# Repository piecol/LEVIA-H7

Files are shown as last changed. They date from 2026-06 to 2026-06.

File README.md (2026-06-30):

# LEVIA H7
Open hardware STM32H743 drone flight controller designed in KiCad.
LEVIA H7 is a six-layer flight controller built around the STM32H743, developed as an open hardware platform for multirotor, fixed-wing and experimental UAV applications.
The repository includes the complete editable KiCad design files, schematics, PCB layout, 3D model, bill of materials and manufacturing files.

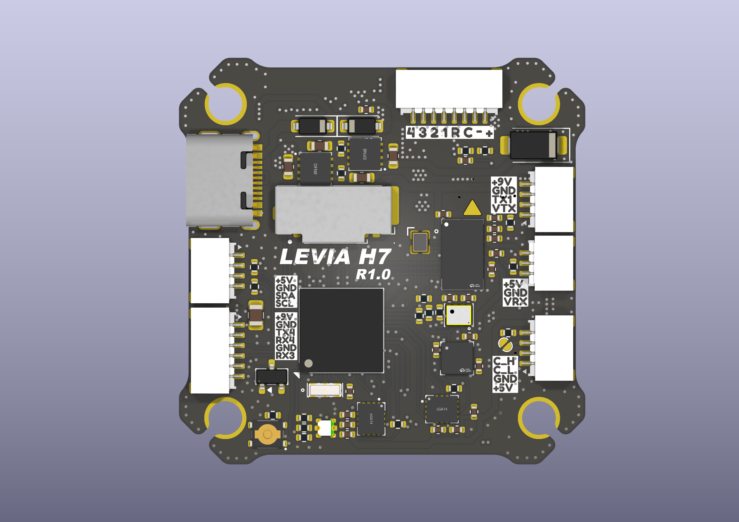
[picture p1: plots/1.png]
Front

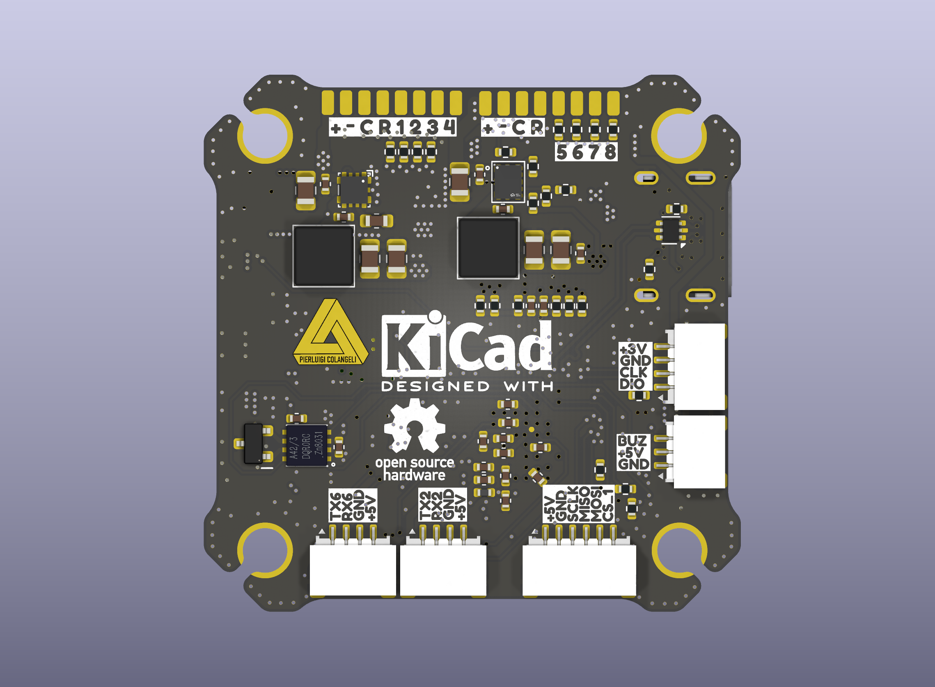
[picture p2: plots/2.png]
Back

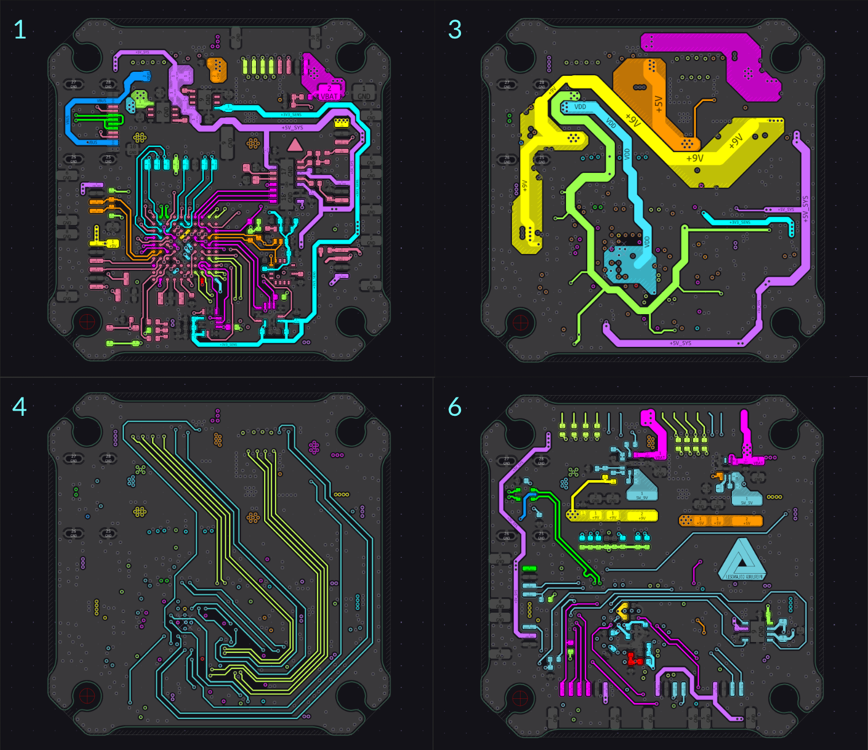
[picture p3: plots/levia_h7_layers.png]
Layers


[!WARNING]
LEVIA H7 is currently an unvalidated hardware design.
Prototype bring-up and flight testing are still pending.
Review the design independently before manufacturing or using it in an aircraft.

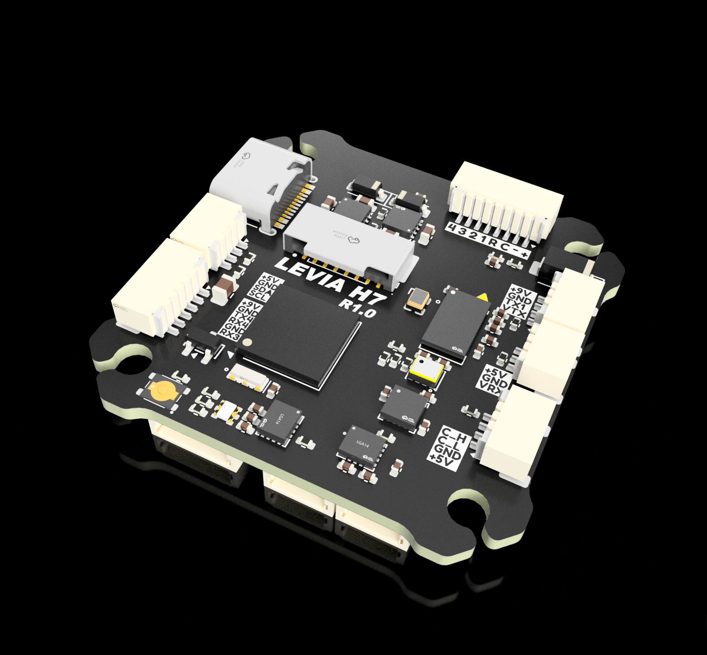
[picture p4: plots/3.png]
Render_F

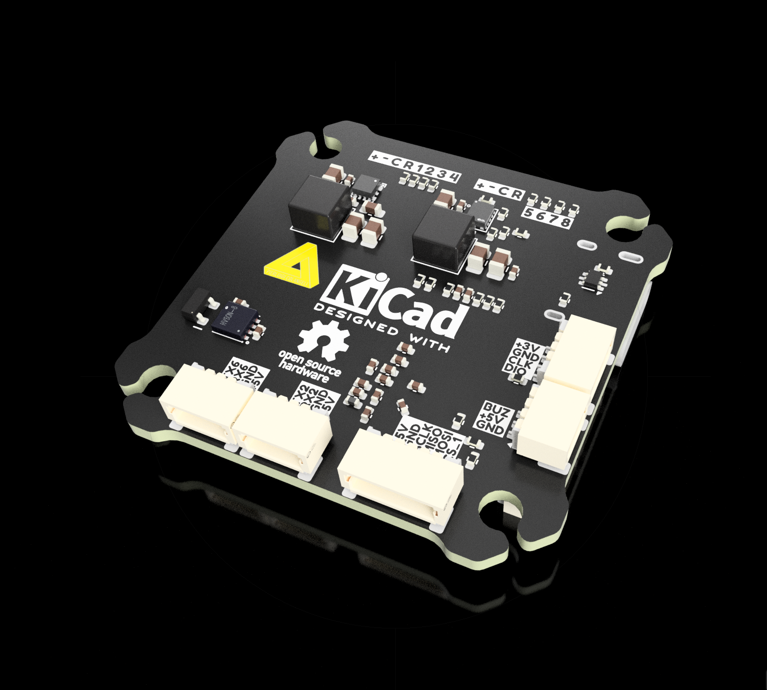
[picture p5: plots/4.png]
Render_B


## Main features

* STM32H743 high-performance microcontroller
* Six-layer PCB
* Eight motor outputs
* Dual ICM-42688-P inertial measurement units
* DPS368 barometric pressure sensor
* IST8310 magnetometer
* microSD interface for onboard logging
* Analog video interface with AT7456E-compatible OSD
* Digital VTX connector for DJI O3/O4-class systems
* CAN interface with selectable 120 Ω termination
* Dedicated RC input connector
* External I²C and SPI expansion connectors
* Two ESC connectors with current sensing and telemetry inputs
* USB-C interface with ESD protection
* Dedicated 5 V and 9 V switching regulators
* Separate 3.3 V regulators for MCU and sensor domains
* Up to 6S battery input

## Project status

The current files should be considered a pre-production engineering revision, not a flight-qualified product.

## Design overview

LEVIA H7 was designed as a general-purpose H7 flight controller rather than as a clone of an existing commercial board.

The architecture follows common flight-controller conventions where useful for firmware compatibility, including standard STM32 peripheral assignments, SDMMC, USB, motor timers and familiar ESC/VTX interfaces.

The following areas were developed independently for LEVIA H7:

* power architecture;
* component placement;
* PCB outline and mechanical design;
* power-distribution network;
* six-layer stackup implementation;
* signal routing;
* grounding strategy;
* design rules and manufacturing preparation.

Publicly available flight-controller schematics, product documentation and firmware hardware definitions were consulted as engineering references.

## Design references

LEVIA H7 is an original KiCad hardware design.

The MatekH743 ArduPilot hardware definition and publicly available flight-controller documentation were used as references for peripheral allocation, firmware compatibility and common interface conventions.

The power architecture, schematic implementation, PCB placement, mechanical design and routing were developed independently.

## Power architecture

LEVIA H7 uses separate power domains for flight-control electronics and external video equipment.

* 5V_SYS supplies the onboard 3.3 V regulators and external low-voltage peripherals.
* 3V3_MCU supplies the STM32H743 and digital logic.
* 3V3_SENS provides a separate supply for onboard sensors.
* 9V is intended for digital video transmitters.
* USB VBUS can power the system through diode OR-ing for configuration and debugging.

The input power architecture supports batteries up to 6S and includes transient-voltage suppression.

## Sensors

Inertial sensing

LEVIA H7 includes two independent ICM-42688-P IMUs connected to separate SPI buses.

The dual-IMU architecture is intended to support sensor redundancy, comparison and firmware-level failover strategies.

## Environmental sensing

The board includes:

* DPS368 barometric pressure sensor;
* IST8310 three-axis magnetometer.

Additional environmental sensing may be considered in future revisions.

## Interfaces

Motor and ESC connections

LEVIA H7 provides two ESC connectors:

* motors 1–4 with current sensing and ESC telemetry;
* motors 5–8 with an independent current input and telemetry UART.

[!CAUTION]
ESC connector pinouts are not universally standardized. Verify VBAT, GND and signal ordering before connecting an ESC.

## Video

The board supports both:

* analog video with onboard OSD;
* digital VTX systems through a dedicated 9 V connector and UART interfaces.

## Expansion

External interfaces include:

* I²C;
* SPI with two chip-select signals;
* CAN;
* UART-based RC input;
* buzzer;
* LED output;
* auxiliary ADC inputs.

The expansion connectors provide 5 V power, while their digital logic operates at 3.3 V.

## PCB

The PCB uses a six-layer stackup with dedicated ground-reference layers.

The layout was developed and documented progressively, with particular attention to:

* uninterrupted signal return paths;
* switching-regulator current loops;
* IMU power integrity;
* separation of analog and switching nodes;
* USB differential routing;
* SDMMC routing;
* motor and telemetry signal grouping.

## Repository contents
```bash
LEVIA-H7/
├── LEVIA_H7.kicad_pro       KiCad project
├── LEVIA_H7.kicad_sch       Top-level schematic
├── LEVIA_H7.kicad_pcb       PCB layout
├── LEVIA_H7.kicad_dru       Custom design rules
├── *.kicad_sch              Hierarchical schematic sheets
├── LEVIA_H7.pdf             Exported schematic
├── LEVIA_H7.step            3D board model
├── bom/                     Bill of materials
├── jlcpcb/                  JLCPCB manufacturing files
├── nextpcb/                 NextPCB manufacturing files
├── plots/                   PCB images and renders
└── LICENSE.txt              CERN-OHL-S-2.0 license
```

## Viewing the design

The project can be opened locally with KiCad 10.

The schematic and PCB can also be inspected directly in a browser through KiCanvas:

KiCanvas: https://kicanvas.org/?repo=https%3A%2F%2Fgithub.com%2Fpiecol%2FLEVIA-H7

No KiCad installation is required for browser-based inspection.

## Manufacturing

Manufacturing exports are included for convenience, but they should not be treated as production-validated files.

Before ordering:

1. review the schematic and PCB independently;
2. verify connector orientation and pin numbering;
3. confirm all selected component variants and footprints;
4. review assembly substitutions;
5. run the latest ERC and DRC;
6. verify the fabrication stackup and controlled-impedance requirements;
7. inspect Gerber and drill files with an independent viewer.

Please use GitHub Issues for review notes, potential errors and proposed improvements.

## License

LEVIA H7 hardware design files are released under the:

CERN Open Hardware Licence Version 2 — Strongly Reciprocal

See LICENSE.txt for the complete license text.

Any redistribution or modified version must comply with the conditions of CERN-OHL-S-2.0.

## Disclaimer

This project is provided without warranty.

LEVIA H7 is experimental hardware intended for engineering, educational and research use.

UAV systems can cause property damage, injury or loss of the aircraft. Anyone manufacturing, modifying or operating this design is responsible for independently validating its safety and regulatory compliance.

⸻

Designed by Pierluigi Colangeli, PhD

Hardware design · Embedded systems · Open hardware

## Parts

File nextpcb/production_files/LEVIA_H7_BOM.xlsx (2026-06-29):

LEVIA_H7
Reference | Qty | Value | MPN | Manufacturer | Footprint | LCSC Part | Datasheet | Notes
C45,C46 | 2 | 10n | CL05B103KB5NNNC | Samsung Electro-Mechanics | Capacitor_SMD:C_0402_1005Metric | C15195 |  | Alternative ok - not critical
C1,C4,C5,C6,C9,C10,C17,C20,C21,C26,C28,C33,C34,C35,C38,C39,C40,C43,C44,C47,C48,C49,C50,C54 | 24 | 100n | GRM022R60J104KE15D | Murata Electronics | Capacitor_SMD:C_0402_1005Metric | C1525 |  | Alternative ok - not critical
C15,C16 | 2 | 100n | GRM022R60J104KE15D | Murata Electronics | Capacitor_SMD:C_0402_1005Metric | C307331 |  | Alternative ok - not critical
C3,C7,C53 | 3 | 1u | CL05A105KA5NQNC | Samsung Electro-Mechanics | Capacitor_SMD:C_0402_1005Metric | C52923 |  | Alternative ok - not critical
C18 | 1 | 1u | CL10A105KB8NNNC | Samsung Electro-Mechanics | Capacitor_SMD:C_0603_1608Metric | C15849 |  | Alternative ok - not critical
C8,C11 | 2 | 2.2u | CL05A225MQ5NSNC | Samsung Electro-Mechanics | Capacitor_SMD:C_0402_1005Metric | C12530 |  | Alternative ok - not critical
L1,L2 | 2 | 2.2u | XGL4020-222MEC | Coilcraft | Inductor_SMD:L_Coilcraft_XAL4030-XXX | C6012410 | ~
C2,C12,C41,C42,C51 | 5 | 4.7u | CL05A475MP5NRNC | Samsung Electro-Mechanics | Capacitor_SMD:C_0402_1005Metric | C23733 |  | Alternative ok - not critical
C29,C30,C31,C32 | 4 | 4.7u | CL10A475KO8NNNC | Samsung Electro-Mechanics | Capacitor_SMD:C_0603_1608Metric | C19666 |  | Alternative ok - not critical
C13,C14 | 2 | 10u | GRM21BR61H106KE43L | Murata Electronics | Capacitor_SMD:C_0805_2012Metric | C440198 |  | Alternative ok - not critical
C36,C37 | 2 | 10u | CL05A106MQ5NUNC | Samsung Electro-Mechanics | Capacitor_SMD:C_0402_1005Metric | C15525 |  | Alternative ok - not critical
C22,C24,C25,C27,C52 | 5 | 22u | CL21A226MAQNNNE | Samsung Electro-Mechanics | Capacitor_SMD:C_0805_2012Metric | C45783 |  | Alternative ok - not critical
R42,R43,R44,R45,R46,R47,R48,R49 | 8 | 10R | 0402WGF100JTCE | UNI-ROYAL(Uniroyal Elec) | Resistor_SMD:R_0402_1005Metric | C25077 |  | Alternative ok - not critical
R22,R23 | 2 | 75R | 0402WGF750JTCE | UNI-ROYAL(Uniroyal Elec) | Resistor_SMD:R_0402_1005Metric | C25133 |  | Alternative ok - not critical
R24 | 1 | 120R | 0402WGF1200TCE | UNI-ROYAL(Uniroyal Elec) | Resistor_SMD:R_0402_1005Metric | C25079 |  | Alternative ok - not critical
R4,R5,R6 | 3 | 220R | 0402WGF2200TCE | UNI-ROYAL(Uniroyal Elec) | Resistor_SMD:R_0402_1005Metric | C25091 |  | Alternative ok - not critical
R11,R34 | 2 | 1K | 0402WGF1001TCE | UNI-ROYAL(Uniroyal Elec) | Resistor_SMD:R_0402_1005Metric | C11702 |  | Alternative ok - not critical
R25,R26,R30,R31 | 4 | 4.7K | 0402WGF4701TCE | UNI-ROYAL(Uniroyal Elec) | Resistor_SMD:R_0402_1005Metric | C25900 |  | Alternative ok - not critical
R1,R2 | 2 | 5.1K | 0402WGF5101TCE | UNI-ROYAL(Uniroyal Elec) | Resistor_SMD:R_0402_1005Metric | C25905 |  | Alternative ok - not critical
R3,R8,R10,R19,R20,R21,R27,R28,R32,R35,R36,R37,R38,R39,R40,R41 | 16 | 10K | 0402WGF1002TCE | UNI-ROYAL(Uniroyal Elec) | Resistor_SMD:R_0402_1005Metric | C25744 |  | Alternative ok - not critical
R16 | 1 | 12.4K | 0402WGF1242TCE | UNI-ROYAL(Uniroyal Elec) | Resistor_SMD:R_0402_1005Metric | C11692 |  | Alternative ok - not critical
R12 | 1 | 16.5k | 0402WGF1652TCE | UNI-ROYAL(Uniroyal Elec) | Resistor_SMD:R_0402_1005Metric | C25857 | ~ | Alternative ok - not critical
R7,R9,R15,R29 | 4 | 100K | 0402WGF1003TCE | UNI-ROYAL(Uniroyal Elec) | Resistor_SMD:R_0402_1005Metric | C25741 | ~ | Alternative ok - not critical
Y1 | 1 | 8MHz | CSTNE8M00GH5C000R0 | muRata(村田) | EasyEDA:OSC-SMD_3P-L3.2-W1.3-P1.20-L | C341525 | https://lcsc.com/product-detail/Others_Murata-Electronics-CSTNE8M00GH5C000R0_C341525.html | Alternative ok - not critical
D3,D4 | 2 | 1N5819WL | 1N5819W | TECH PUBLIC | Diode_SMD:D_SOD-123 | C2905650 | https://datasheet.lcsc.com/lcsc/2204281430_Guangdong-Hottech-1N5819WS_C191023.pdf | Alternative ok - not critical
FB1 | 1 | 600Ω@100MHz | FCM1608KF-601T02 | TAI-TECH | Inductor_SMD:L_0402_1005Metric | C127281 |  | Alternative ok - not critical
U9 | 1 | AT7456ELAH | AT7456ELAH | 杭州中科微 | EasyEDA:LGA-16_L6.8-W4.0-P0.65-TL-2EP | C42388749 | https://www.lcsc.com/datasheet/C42388749.pdf
Q1 | 1 | AO3400A | AO3400A | Alpha & Omega Semicon | Package_TO_SOT_SMD:SOT-23 | C20917 | http://www.aosmd.com/pdfs/datasheet/AO3400A.pdf | Alternative ok - not critical
U6,U7 | 2 | AP7361C-33FGE-7 | AP7361C-33FGE-7 | DIODES(美台) | EasyEDA:DFN-8_L3.0-W3.0-P0.65-BL-EP | C151007 | https://lcsc.com/product-detail/Low-Dropout-Regulators-LDO_DIODES_AP7361C-33FGE-7_AP7361C-33FGE-7_C151007.html
U16 | 1 | DPS368XTSA1 | DPS368XTSA1 | Infineon(英飞凌) | EasyEDA:LGA-8_L2.5-W2.0-P0.65-TR_DPS368 | C3232508 | https://www.lcsc.com/datasheet/C3232508.pdf
USB1 | 1 | HC-TYPE-C-16P-01M | HC-TYPE-C-16P-01M | HCTL | EasyEDA:USB-C-SMD_HCTL_HC-TYPE-C-16P-01M | C2894899 |  | Alternative ok - not critical
U14,U15 | 2 | ICM-42688-P | ICM-42688-P | TDK InvenSense(应美盛) | EasyEDA:LGA-14_L3.0-W2.5-P0.50-TL | C1850418 | https://www.lcsc.com/datasheet/C1850418.pdf
U17 | 1 | IST8310 | IST8310 | iSentek | EasyEDA:LGA-16_L3.0-W3.0-P0.50-BL_SQ | C2683055 | https://www.lcsc.com/datasheet/C2683055.pdf
D1 | 1 | LED_RGB_EP | 19-337/R6GHBHC-M01/2T | EVERLIGHT(亿光) | EasyEDA:LED-ARRAY-SMD_6P-L1.6-W1.6-TL | C131204 | https://lcsc.com/product-detail/Light-Emitting-Diodes-LED_Everlight-Elec-19-337-R6GHBHC-M01-2T_C131204.html | Alternative ok - not critical
U4 | 1 | LMR43620R5RPER | LMR43620R5RPER | TI(德州仪器) | EasyEDA:VQFN-9_L2.1-W2.1-P0.50-TL | C32712896 | https://www.lcsc.com/datasheet/C32712896.pdf
U5 | 1 | LMR604303SRAKRQ1 | LMR604303SRAKRQ1 | TI(德州仪器) | EasyEDA:WQFN-9_L2.5-W2.0_RAK0009A | C49292342 | https://www.lcsc.com/datasheet/C49292342.pdf
D6 | 1 | PESD2CAN | PESD2CANFD24V-TR | Nexperia | PCM_Package_TO_SOT_SMD_AKL:SOT-23 | C552486 | https://www.tme.eu/Document/ad02fbf39ace74a5161accc984238198/PESD2CAN.pdf
SW2 | 1 | RKCGG140SMTRLFS | RKCGG140SMTRLFS | C&K | EasyEDA:SW-SMD_4P-L3.0-W2.6-P1.80-LS3.5 | C2927792 | https://www.lcsc.com/datasheet/C2927792.pdf | Alternative ok - not critical
U12 | 1 | SIT1051TK/3 | TJA1051TK/3,118 | NXP(恩智浦) | EasyEDA:HVSON-8_L3.0-W3.0-P0.65-BL-EP | C124020 | https://lcsc.com/product-detail/CAN_NXP_TJA1051TK-3-118_TJA1051TK-3-118_C124020.html | Alternative ok - not critical
D2 | 1 | SMAJ30CA | SMAJ30CA-13-F | Diodes Incorporated | Diode_SMD:D_SMA | C134980 | https://www.littelfuse.com/media?itemid=75e32973-b177-4ee3-a0ff-cedaf1abdb93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 | Alternative ok - not critical
U2 | 1 | STM32H743VIHx | STM32H743VIH6 | STMicroelectronics | Package_BGA:TFBGA-100_8x8mm_Layout10x10_P0.8mm | C964146 | https://www.st.com/resource/en/datasheet/stm32h743vi.pdf
J1 | 1 | TF-028-H265 | TF-028-H265 | HANBO(汉博) | EasyEDA:TF-SMD_TF-021B-H265 | C5310496 | https://www.we-online.com/components/products/datasheet/693072010801.pdf | Alternative ok - not critical
U1 | 1 | USBLC6-2P6 | TPUSBLC6-2P6 | TECH PUBLIC | Package_TO_SOT_SMD:SOT-666 | C2682291 | https://www.st.com/resource/en/datasheet/usblc6-2.pdf | Alternative ok - not critical
Y2 | 1 | XL7EL89COI-111YLC-27M | XL7EL89COI-111YLC-27M | YXC(扬兴晶振) | Crystal:Crystal_SMD_2016-4Pin_2.0x1.6mm | C18214311 | https://www.lcsc.com/datasheet/C18214311.pdf | Alternative ok - not critical
U11,U21 | 2 | ZX-SH1.0-3PWT | ZX-SH1.0-3PWT | Megastar(兆星) | EasyEDA:CONN-SMD_3P-P1.00_MEGASTAR_ZX-SH1.0-3PWT | C7430445 | https://www.lcsc.com/datasheet/C7430445.pdf | Alternative ok - not critical
U3,U8,U10,U13,U18,U24 | 6 | ZX-SH1.0-4PWT | ZX-SH1.0-4PWT | Megastar(兆星) | EasyEDA:CONN-SMD_4P-P1.00_MEGASTAR_ZX-SH1.0-4PWT | C7430446 | https://www.lcsc.com/datasheet/C7430446.pdf | Alternative ok - not critical
U19,U20 | 2 | ZX-SH1.0-6PWT | ZX-SH1.0-6PWT | Megastar(兆星) | EasyEDA:CONN-SMD_6P-P1.00_MEGASTAR_ZX-SH1.0-6PWT | C7430448 | https://www.lcsc.com/datasheet/C7430448.pdf | Alternative ok - not critical
U22 | 1 | ZX-SH1.0-8PWT | ZX-SH1.0-8PWT | Megastar(兆星) | EasyEDA:CONN-SMD_8P-P1.00_MEGASTAR_ZX-SH1.0-8PWT | C7430450 | https://www.lcsc.com/datasheet/C7430450.pdf | Alternative ok - not critical

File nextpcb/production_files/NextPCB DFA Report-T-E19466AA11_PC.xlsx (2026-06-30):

NEXTPCB DFA report
Project Number：LEVIA_H7 |  | Prepared by: chunxiang |  |  |  |  | Date: 20260630
Item | Problem description 问题描述 | Reference location 影响位置 | MPN 物料名称 | Impact 影响 | Image 图片 | NextPCB Suggestion 建议 | Customer feedback 客户反馈 |  | Severity 严重度 | Status 状态
1 | The clearance is too big in Gerber. | U1 | / | The component can't be 100% soldered on the board, which will cause soldeirng issue. |  | Please modify the clearance to 0.7mm. |  | Changed footprint to better match component | Middle
2 | Could you please provide the dimension of 19-337/R6GHBHC-M01/2T? We can't find it from internet. | D1 | / | We are not sure whether the component can be 100% soldered or not, it seems the clearance is too big. |  | Please confirm the footprint or modify the clearance to 0.15mm. |  | The footprint looks fine, it should be compliant with the manufacturer specs https://www.everlighteurope.com/product-details?id=3322&name=19-337%2FR6GHBHC-M01%2F2T&category=Visible+SMD | Middle
3 | The pcakage is 01005 while the footprint is 0402. | C15,C16 C1,C4,C5,C6,C9,C10,C17,C20,C21,C26,C28,C33,C34,C35,C38,C39,C40,C43,C44,C47,C48,C49,C50,C54 | / | Can't be soldered at all. |  | Please modify the footprint to 01005 or provide a new part number which package is 0402. |  | Samsung Electro-Mechanics - CL05B104KB54PNC - C307331 | High
4 | The pad in Gerber is not match with datasheet. | J1 | / | The component may can't be 100% soldered on the board, which will cause soldeirng issue. |  | Please modify the pad accoridng to datasheet. | Modified according to data sheet |  | Middle
5 | The package is 0603 while the footprint is 0402. | FB1 | / | The pad is too small. |  | Please modify the footprint to 0603 or provide a new part number which package is 0402. |  | Murata Electronics - BLM15BD601SN1D - C337875 | High
6 | When you placed the order you chose tented vias while there are vias in the pads, see attach. | via processing | / | The tin may flow into the vias and cause soldeirng issue. |  | Please remove these vias from the pads. | Removed vias as suggested |  | Middle
7 | Is there any soldering direction requirement for L1,L2? | L1,L2 | / | The silk is not clear so we are not sure. |  | Please confirm. |  | Pin1 of the two inductors faces the north side, I added a small silkscreen segment as mark | Middle

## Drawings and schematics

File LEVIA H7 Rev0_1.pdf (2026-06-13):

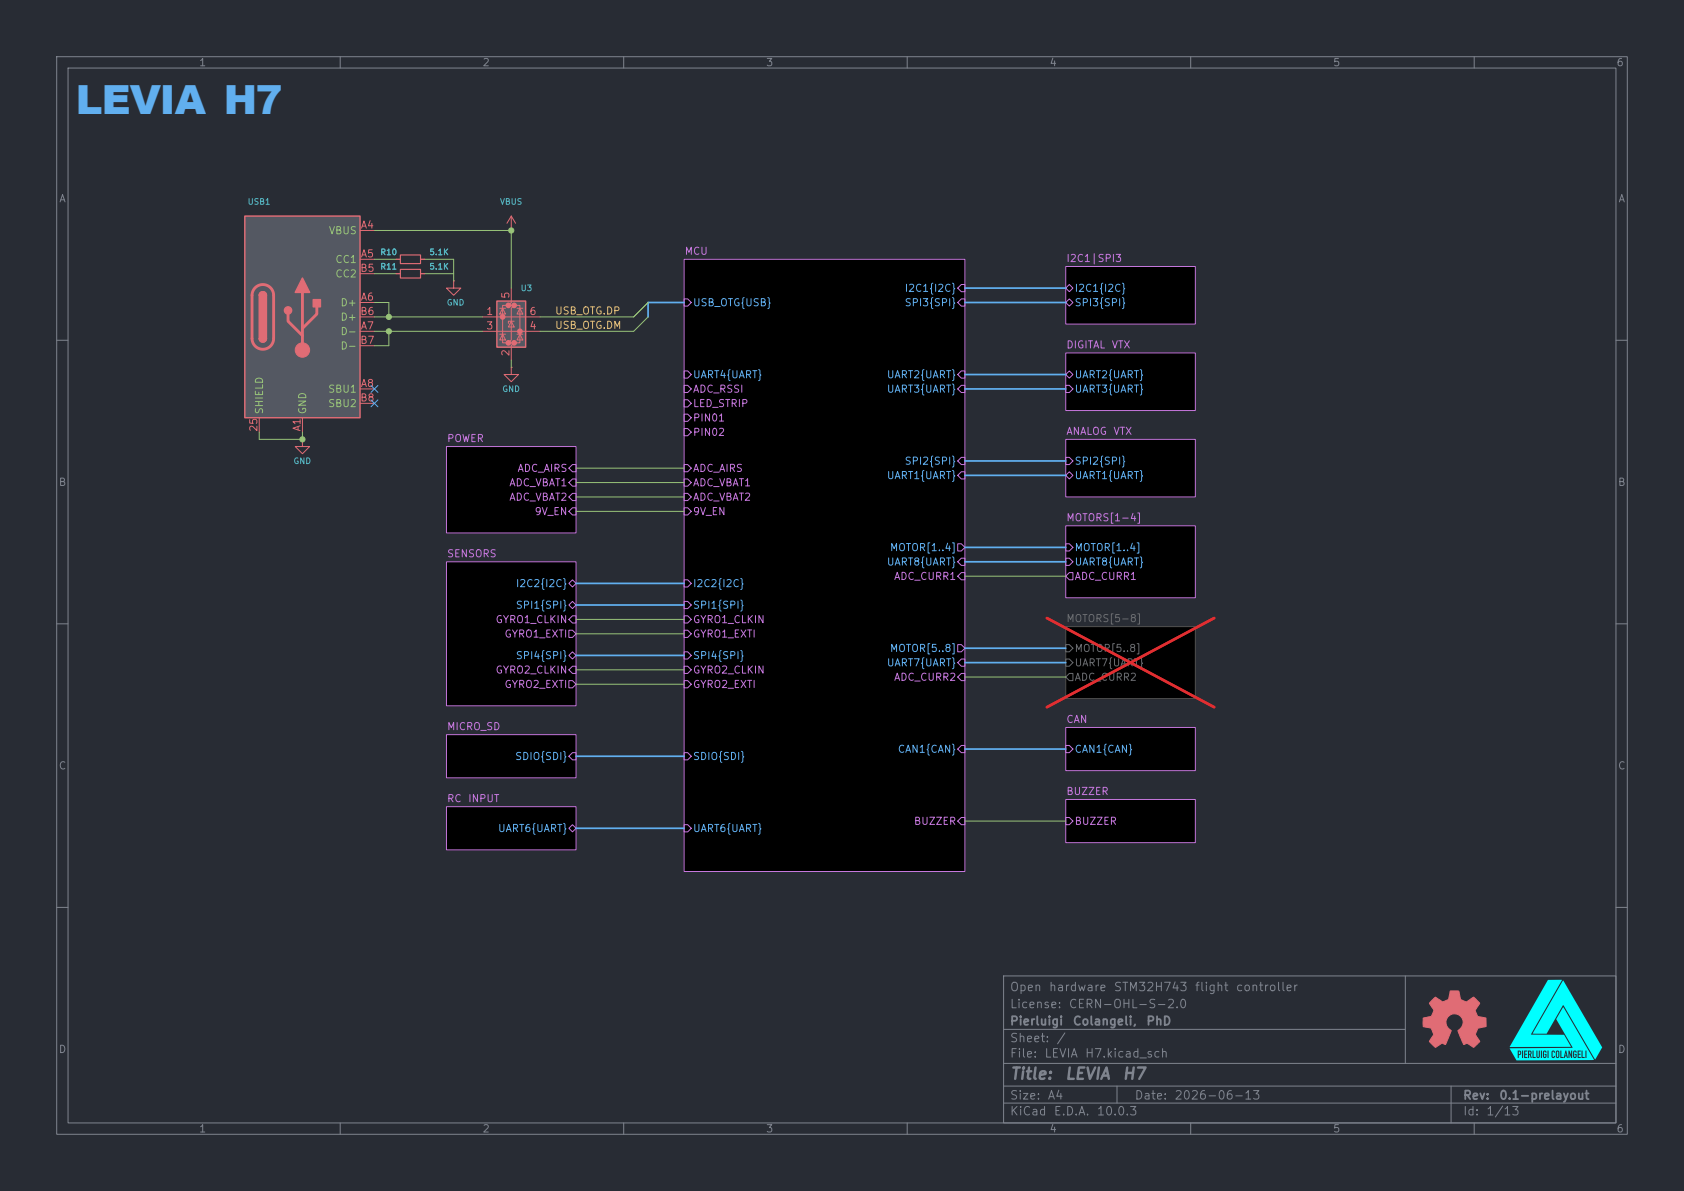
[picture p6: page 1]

Open hardware STM32H743 flight controller
License: CERN-OHL-S-2.0
Pierluigi Colangeli, PhD
Sheet: /
File: LEVIA H7.kicad_sch
Title: LEVIA H7

Size: A4 | Rev: 0.1-prelayout
KiCad E.D.A. 10.0.3 | Id: 1/13

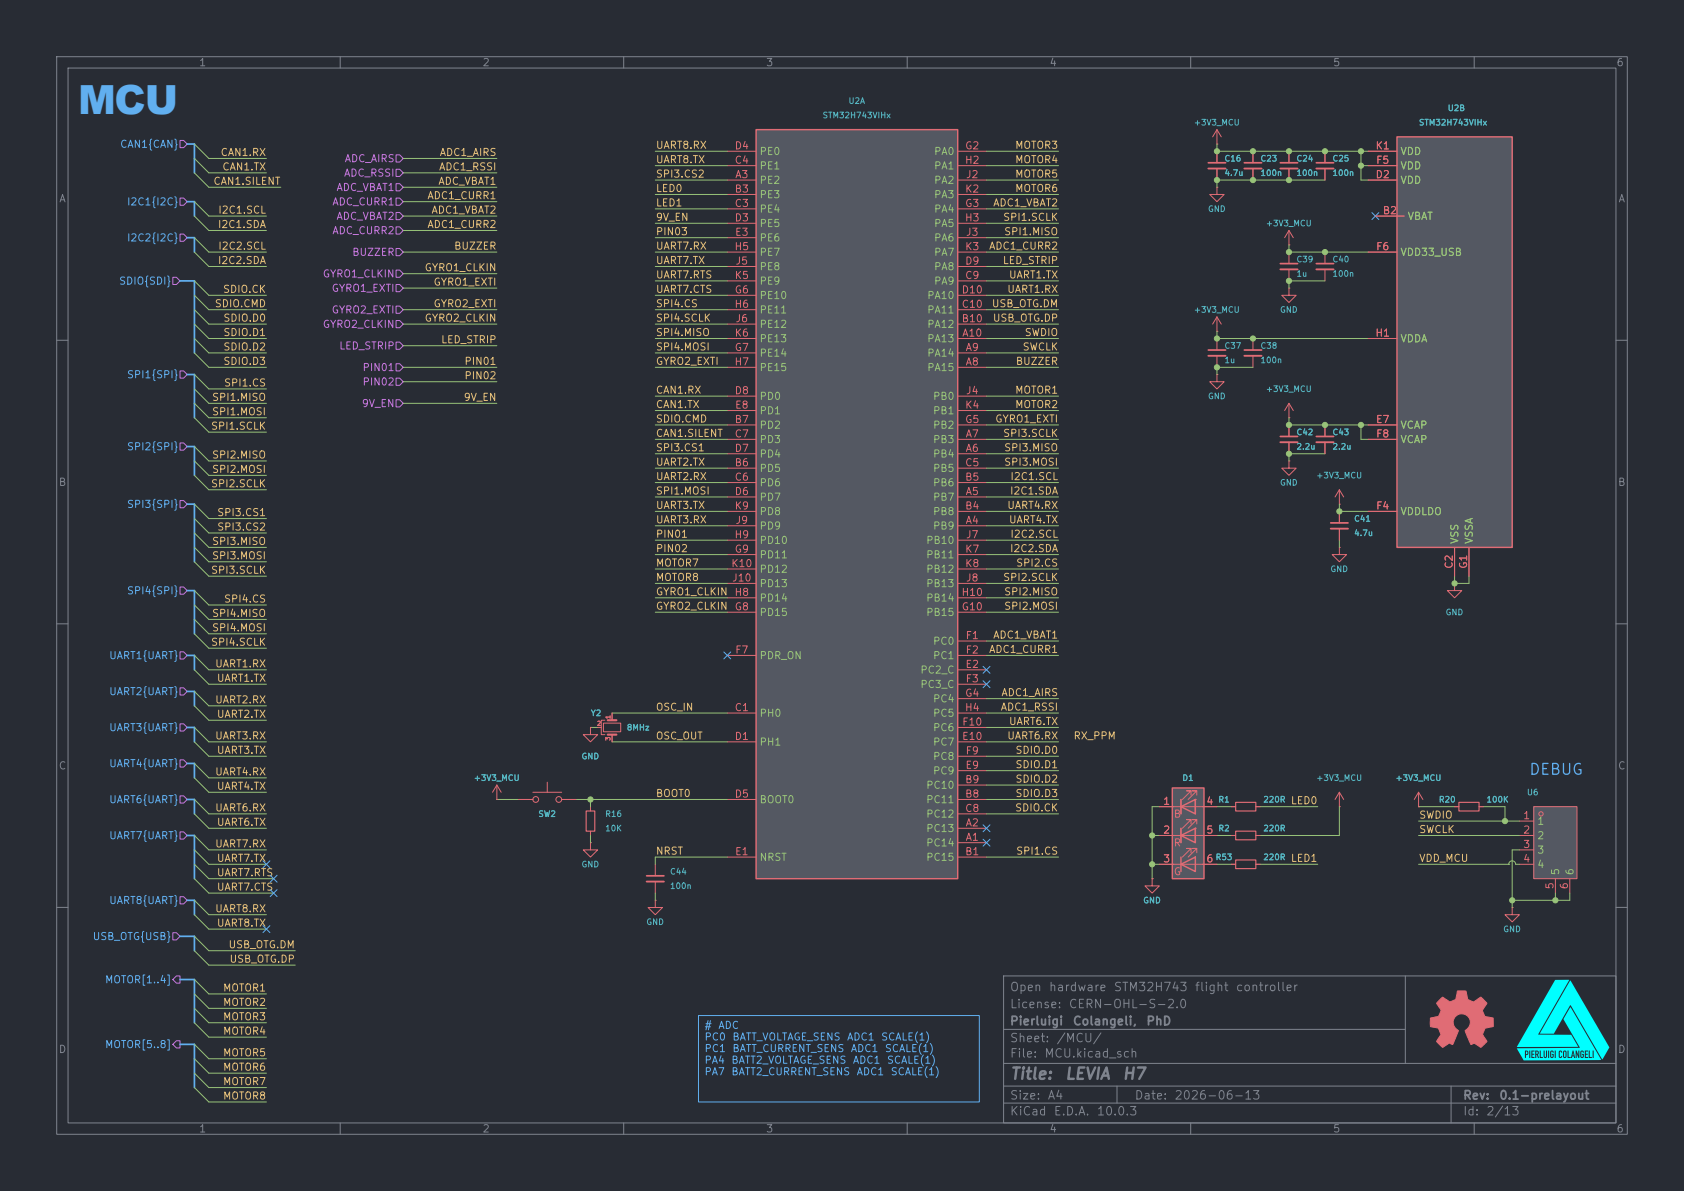
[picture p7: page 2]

PC0 BATT_VOLTAGE_SENS ADC1 SCALE(1) PC1 BATT_CURRENT_SENS ADC1 PA4 BATT2_VOLTAGE_SENS ADC1 PA7 BATT2_CURRENT_SENS ADC1 MCU
UART1.TX CAN1.SILENT SDIO.CK

SPI4.SCLK
ADC1_CURR1 UART7.RX UART6.RX UART3.TX UART4.RX

Open hardware STM32H743 flight controller
License: CERN-OHL-S-2.0
Pierluigi Colangeli, PhD
Sheet: /MCU/
File: MCU.kicad_sch
Title: LEVIA H7

Size: A4 | Rev: 0.1-prelayout
KiCad E.D.A. 10.0.3 | Id: 2/13

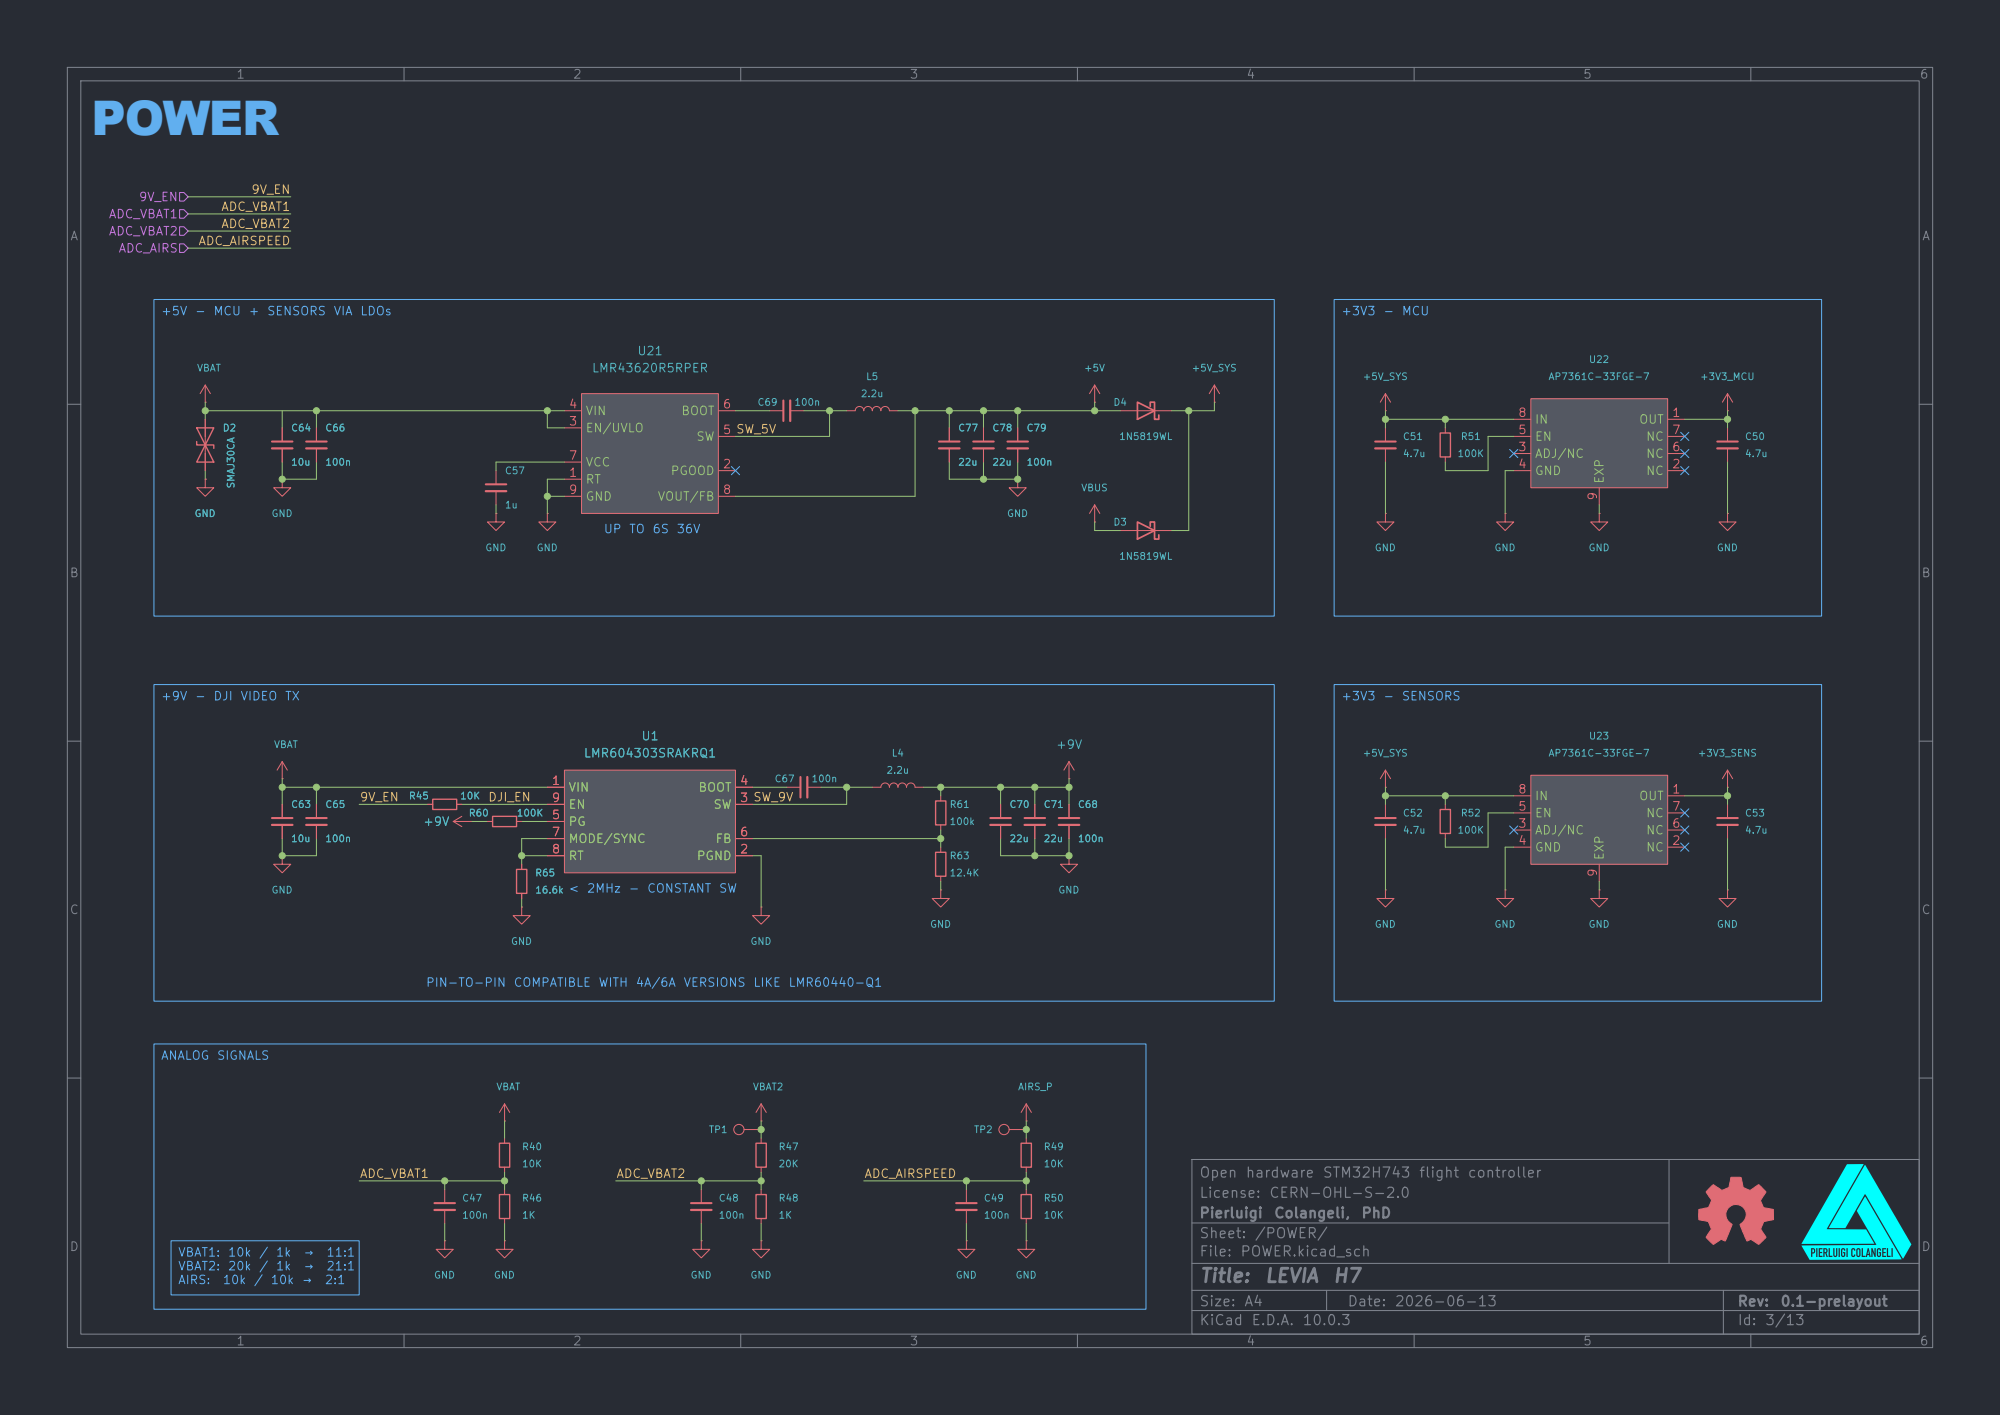
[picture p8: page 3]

Open hardware STM32H743 flight controller +9V

Size: A4 | Rev: 0.1-prelayout
KiCad E.D.A. 10.0.3 | Id: 3/13

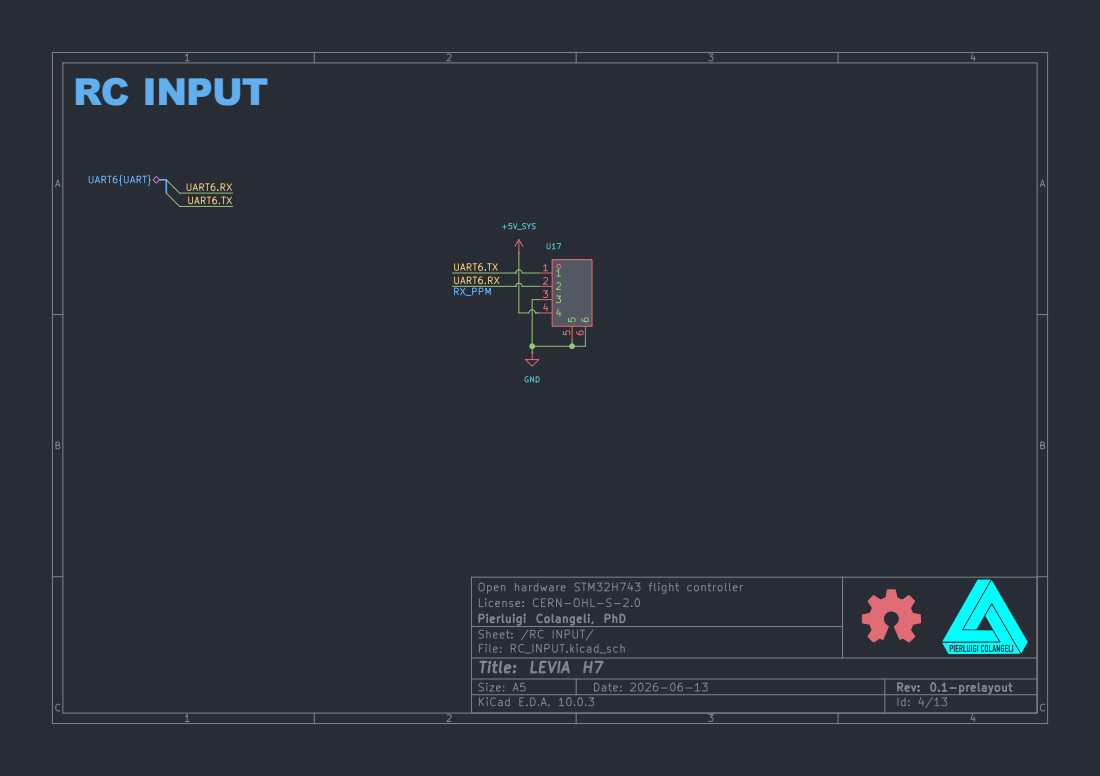
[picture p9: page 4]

Open hardware STM32H743 flight controller 1
RX_PPM

Size: A5 | Rev: 0.1-prelayout | C Date: 2026-06-13
KiCad E.D.A. 10.0.3 | Id: 4/13

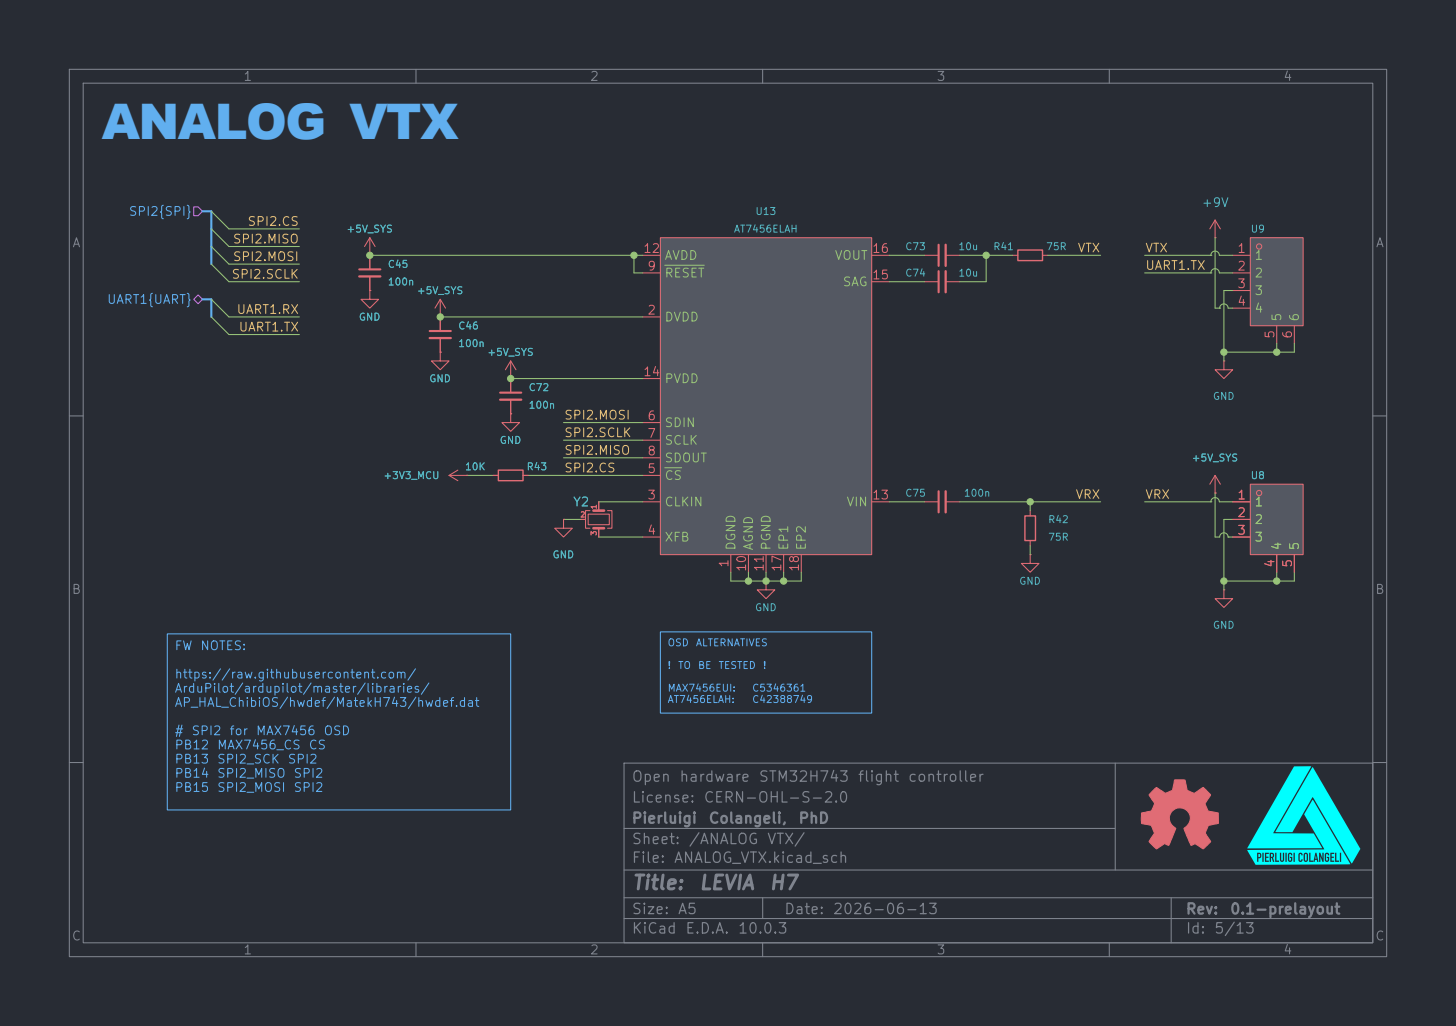
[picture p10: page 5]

Open hardware STM32H743 flight controller DGND

ArduPilot/ardupilot/master/libraries/
AP_HAL_ChibiOS/hwdef/MatekH743/hwdef.dat

Size: A5 | Rev: 0.1-prelayout | C Date: 2026-06-13
KiCad E.D.A. 10.0.3 | Id: 5/13

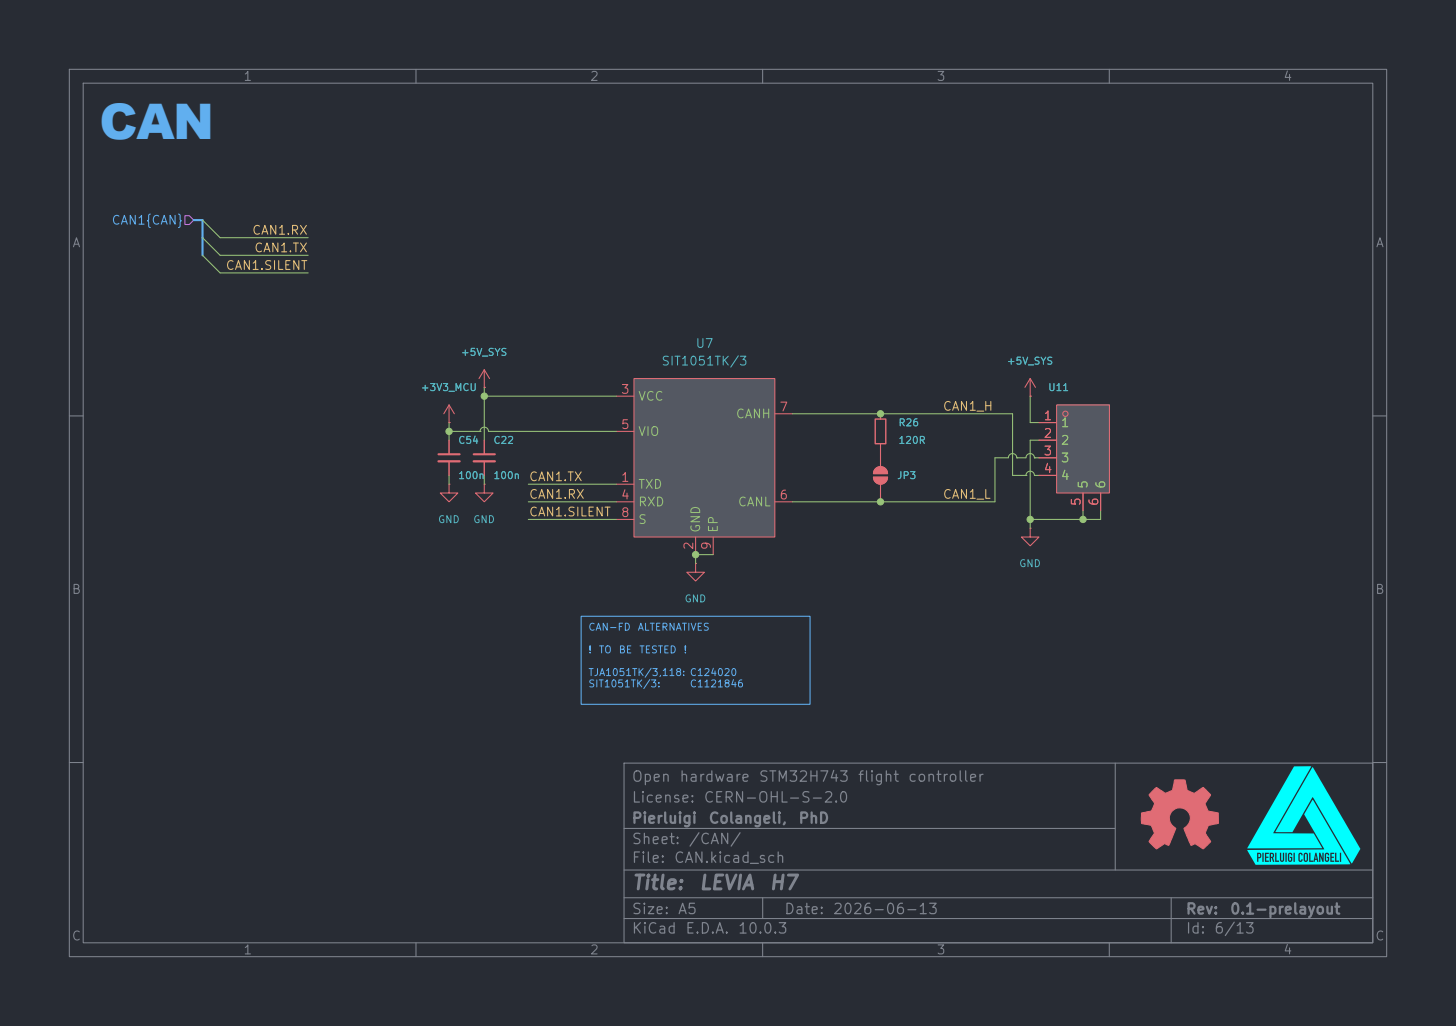
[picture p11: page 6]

Size: A5 | Rev: 0.1-prelayout | C Date: 2026-06-13
KiCad E.D.A. 10.0.3 | Id: 6/13

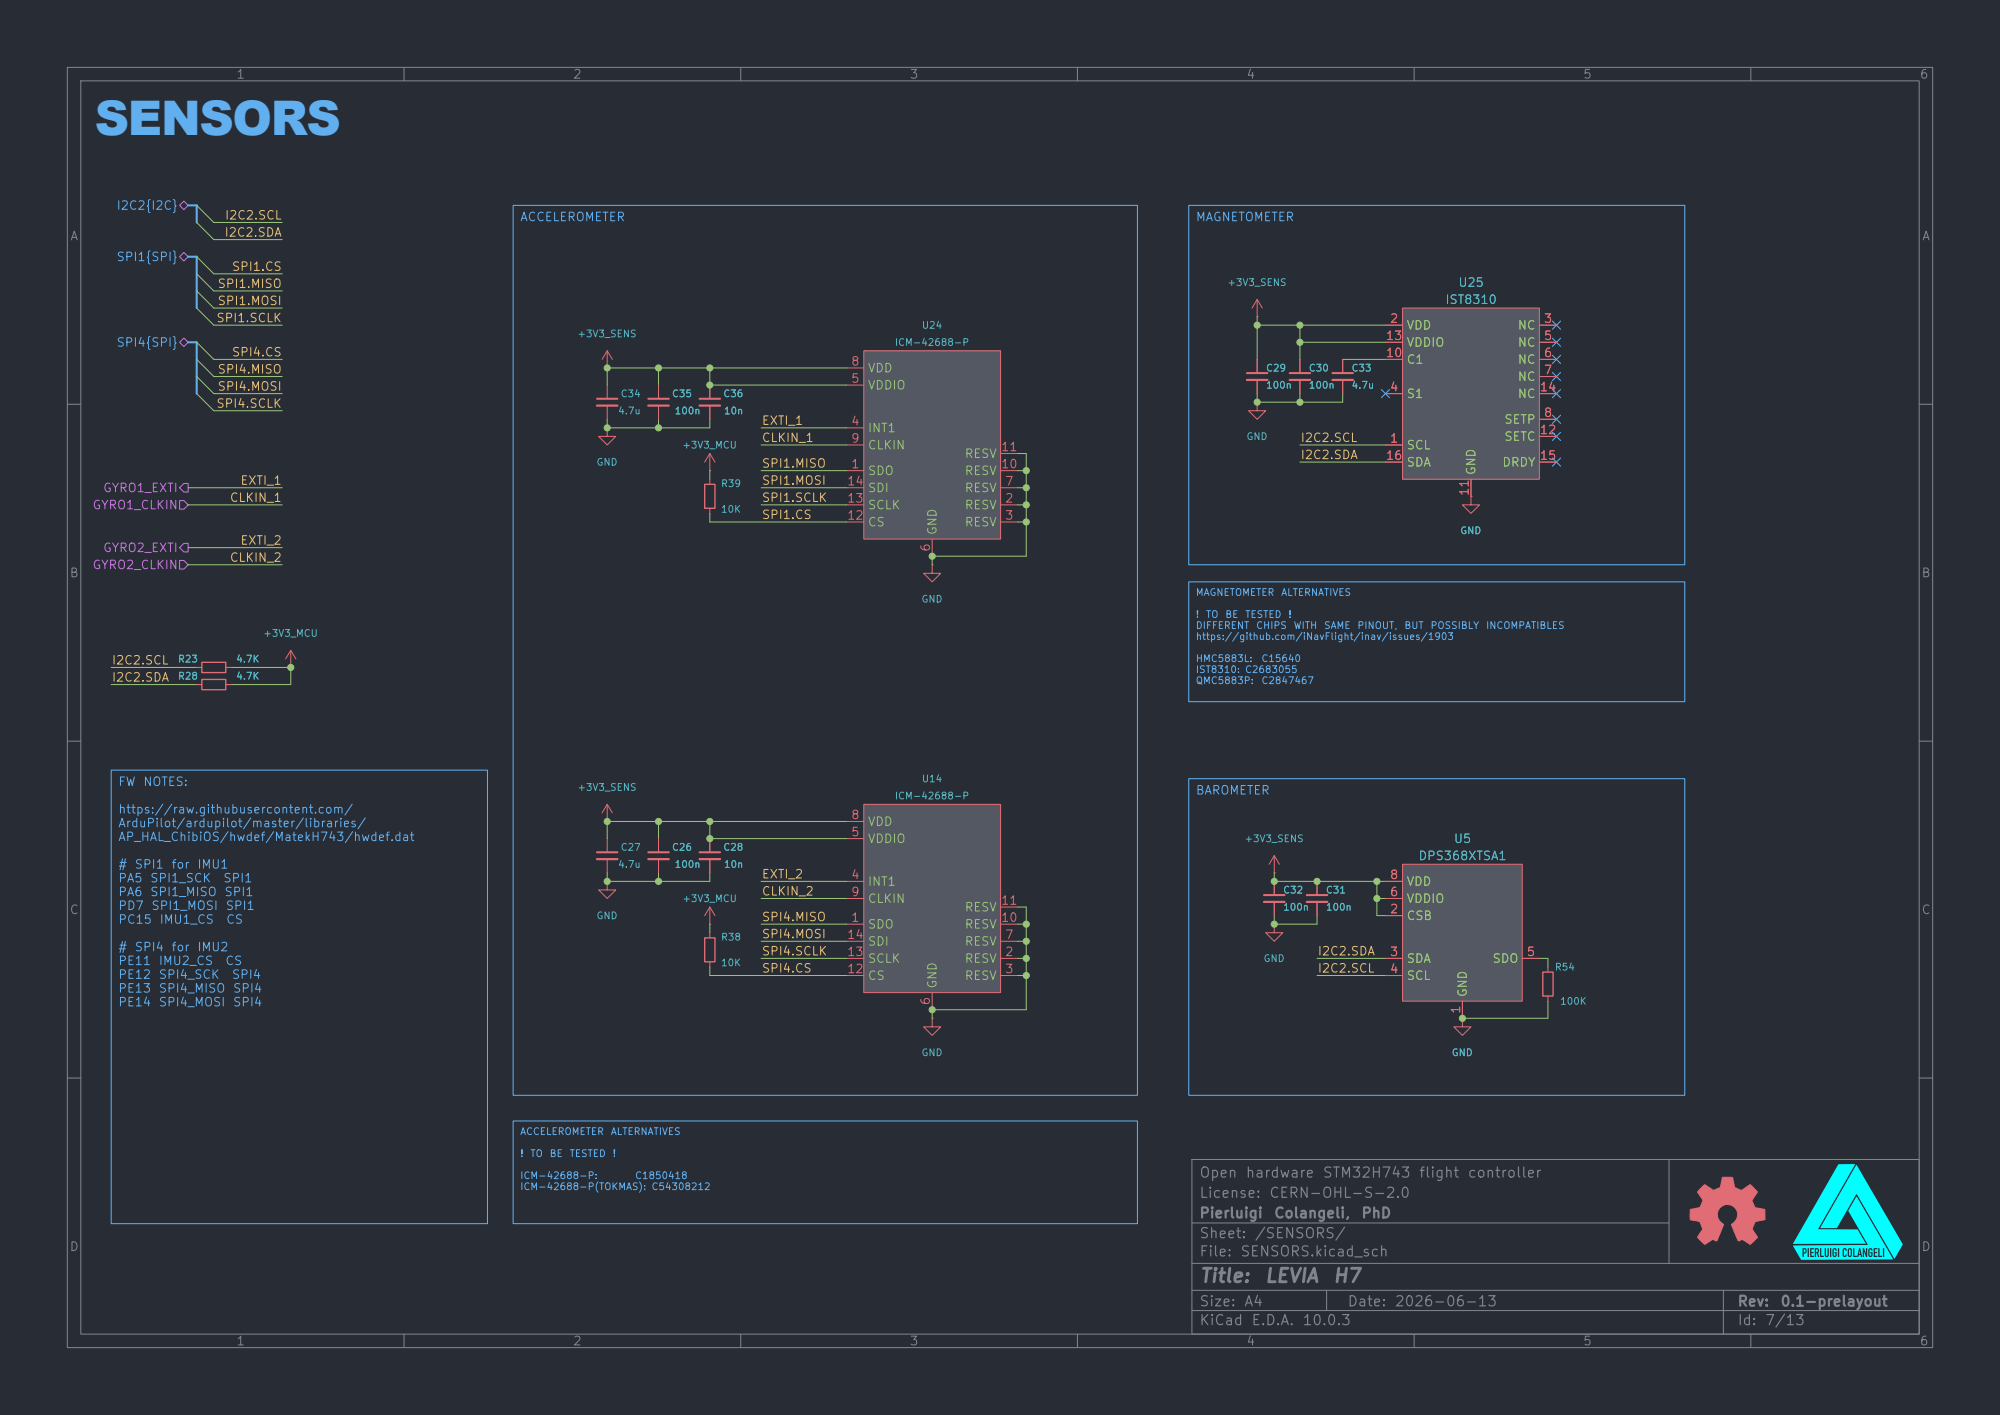
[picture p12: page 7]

4.7u GYRO1_EXTI GYRO2_CLKIN
SPI4.MOSI FW NOTES: https://raw.githubusercontent.com/

! TO BE TESTED ! DIFFERENT CHIPS WITH SAME PINOUT, BUT POSSIBLY INCOMPATIBLES

https://github.com/iNavFlight/inav/issues/1903 HMC5883L: C15640

ArduPilot/ardupilot/master/libraries/
AP_HAL_ChibiOS/hwdef/MatekH743/hwdef.dat

# SPI1 for IMU1 PA5 SPI1_SCK SPI1 PA6 SPI1_MISO SPI1 PD7 SPI1_MOSI SPI1 PC15 IMU1_CS CS # SPI4 for IMU2 PE11 IMU2_CS CS PE12 SPI4_SCK SPI4 PE13 SPI4_MISO SPI4 PE14 SPI4_MOSI SPI4

Open hardware STM32H743 flight controller
License: CERN-OHL-S-2.0
Pierluigi Colangeli, PhD
Sheet: /SENSORS/
File: SENSORS.kicad_sch
Title: LEVIA H7

Size: A4 | Rev: 0.1-prelayout
KiCad E.D.A. 10.0.3 | Id: 7/13

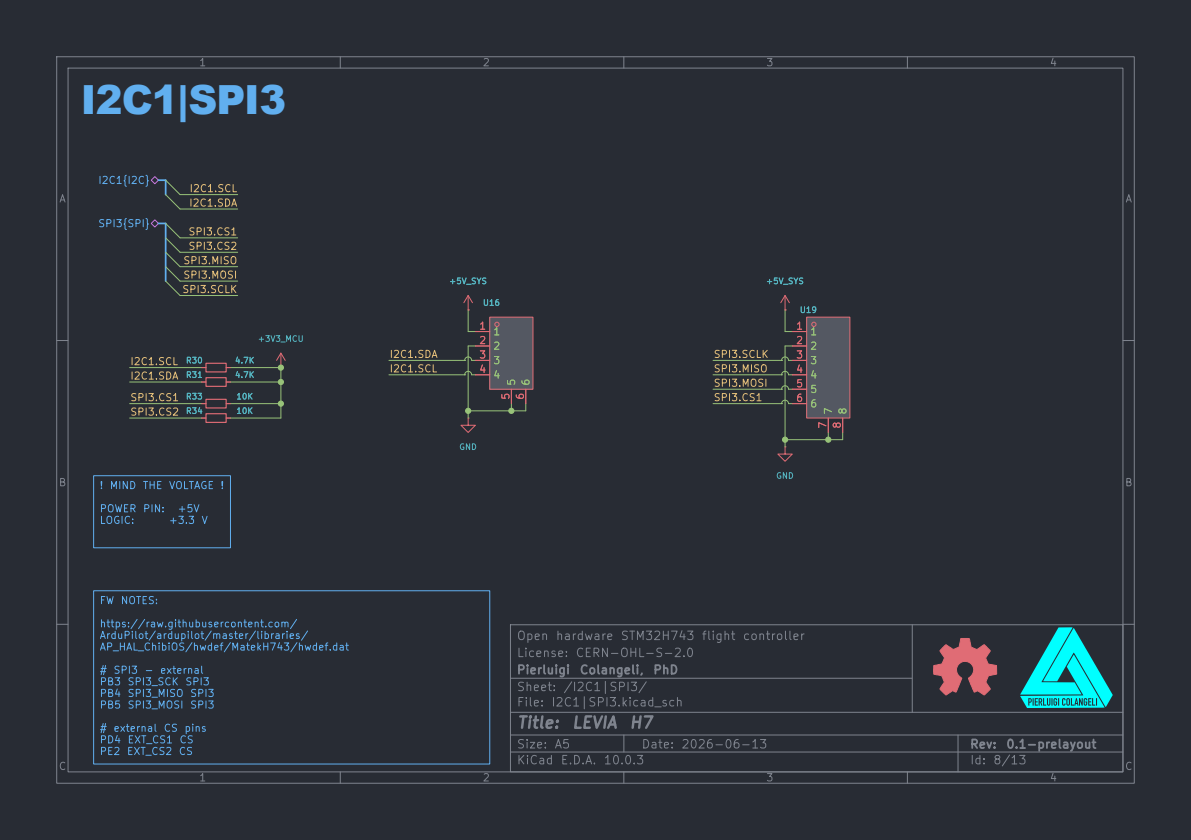
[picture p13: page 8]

Open hardware STM32H743 flight controller GND

FW NOTES: https://raw.githubusercontent.com/

ArduPilot/ardupilot/master/libraries/
AP_HAL_ChibiOS/hwdef/MatekH743/hwdef.dat

# SPI3 - external PB3 SPI3_SCK SPI3 PB4 SPI3_MISO SPI3 PB5 SPI3_MOSI SPI3 # external CS pins PD4 EXT_CS1 CS PE2 EXT_CS2 CS

Size: A5 | Rev: 0.1-prelayout | C Date: 2026-06-13
KiCad E.D.A. 10.0.3 | Id: 8/13

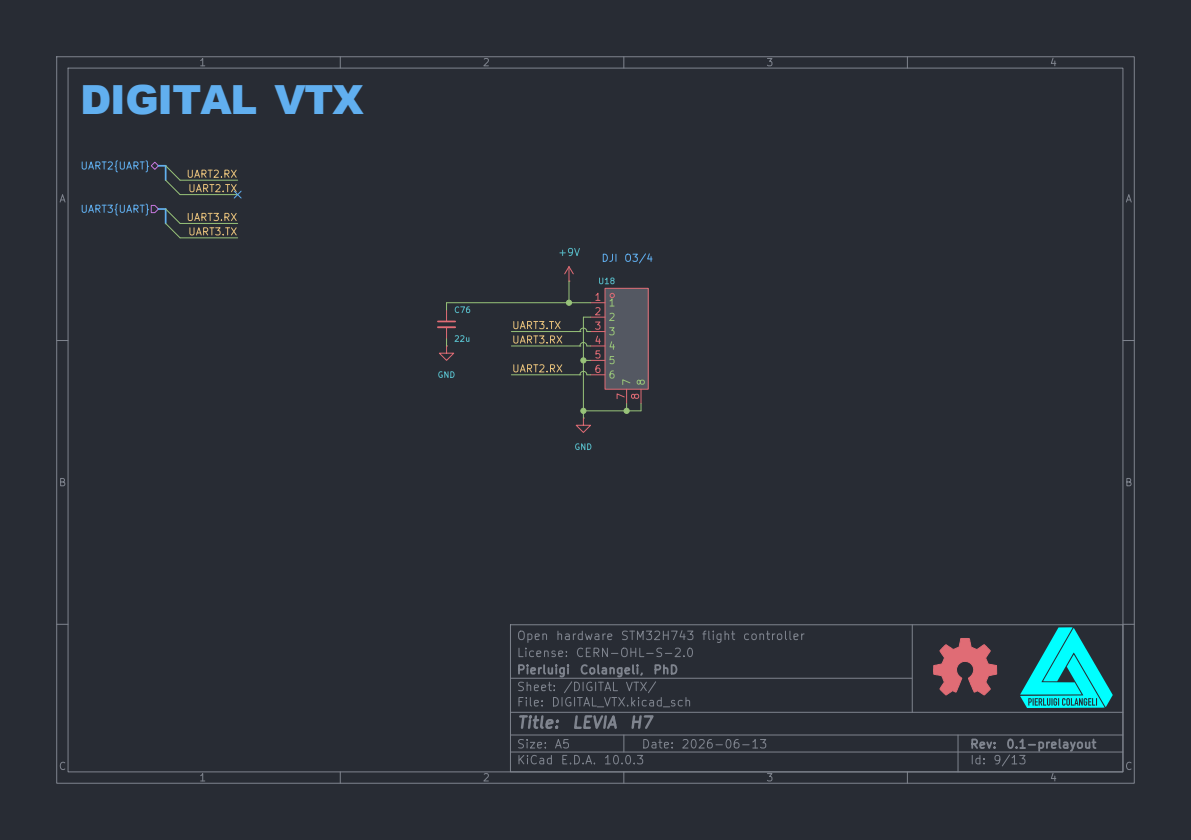
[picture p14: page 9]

Size: A5 | Rev: 0.1-prelayout | C Date: 2026-06-13
KiCad E.D.A. 10.0.3 | Id: 9/13

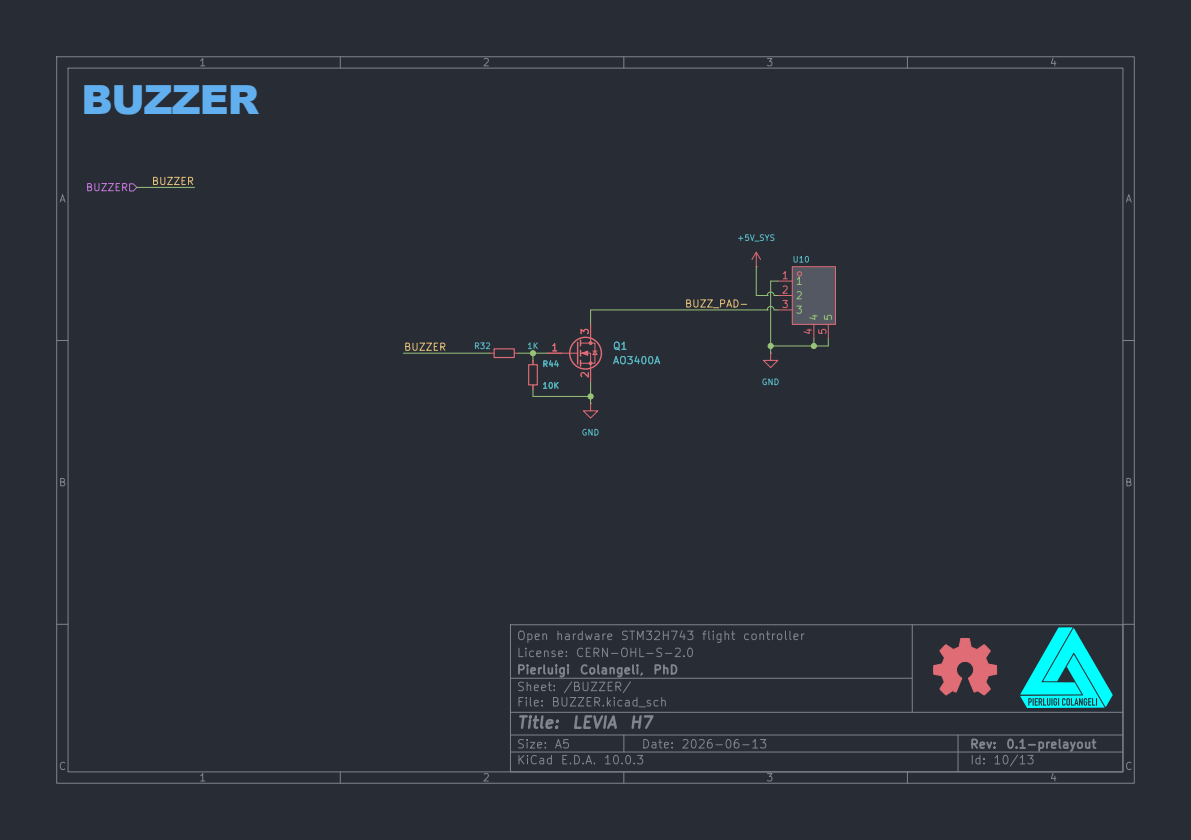
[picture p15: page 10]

Size: A5 | Rev: 0.1-prelayout | C Date: 2026-06-13
KiCad E.D.A. 10.0.3 | Id: 10/13

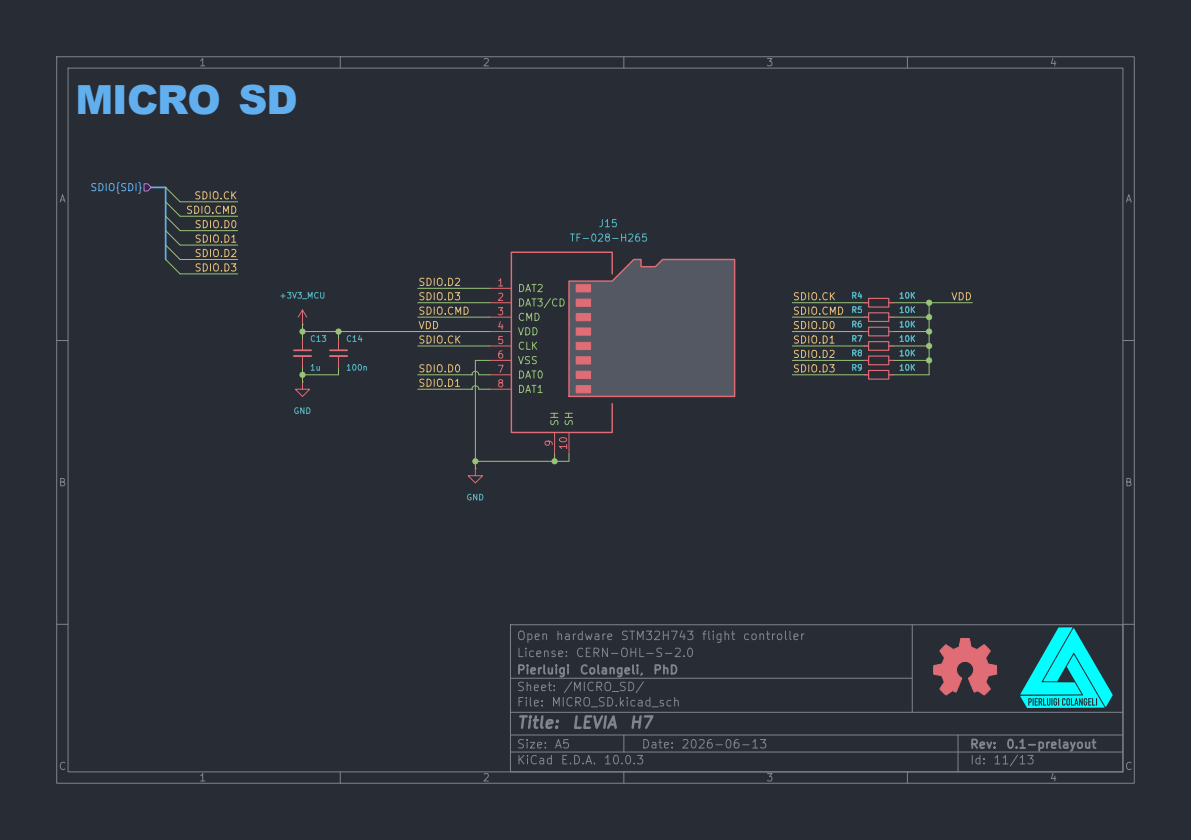
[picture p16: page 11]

Size: A5 | Rev: 0.1-prelayout | C Date: 2026-06-13
KiCad E.D.A. 10.0.3 | Id: 11/13

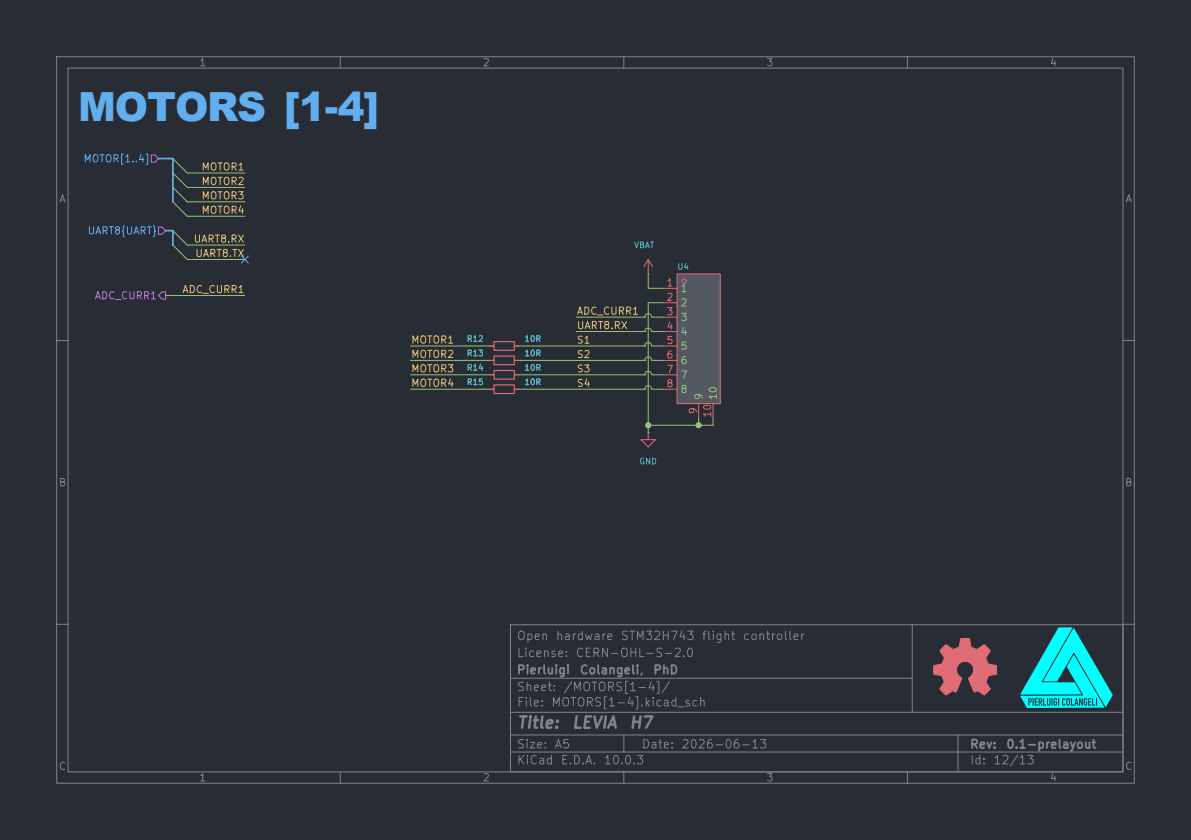
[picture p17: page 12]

Size: A5 | Rev: 0.1-prelayout | C Date: 2026-06-13
KiCad E.D.A. 10.0.3 | Id: 12/13


Open hardware STM32H743 flight controller 1

Size: A5 | Rev: 0.1-prelayout | C Date: 2026-06-13
KiCad E.D.A. 10.0.3 | Id: 13/13

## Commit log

2026-06-14 basic psc shape created
    [LEVIA_H7.kicad_pcb]
2026-06-14 grouped ICs and passives
    [ANALOG_VTX.kicad_sch, BUZZER.kicad_sch, CAN.kicad_sch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]
2026-06-14 showcase functional blocks on PCB
    [LEVIA_H7.kicad_pcb]
2026-06-14 defined stackup
    [LEVIA_H7.kicad_pcb, LEVIA_H7.kicad_sch]
2026-06-14 added net ties for MCU power
    [LEVIA_H7.kicad_pcb, MCU.kicad_sch]
2026-06-14 MORE LAYOUT TESTS
    [DIGITAL_VTX.kicad_sch, LEVIA_H7.kicad_pcb, LEVIA_H7.kicad_sch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]
2026-06-14 more layout
    [LEVIA_H7.kicad_pcb, LEVIA_H7.kicad_sch, MCU.kicad_sch]
2026-06-15 fix usb diff pair suffix
    [LEVIA_H7.kicad_pcb, LEVIA_H7.kicad_sch]
2026-06-23 via resizing
    [LEVIA_H7.kicad_pcb, MCU.kicad_sch]
2026-06-27 wip PDN
    [CAN.kicad_sch, LEVIA_H7.kicad_pcb]
2026-06-27 b fab layer text edit
    [LEVIA_H7.kicad_pcb]
2026-06-28 first drc pass
    [LEVIA_H7.kicad_pcb]
2026-06-28 BOM complete and JLC prod files generated
    [ANALOG_VTX.kicad_sch, BUZZER.kicad_sch, CAN.kicad_sch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]
2026-06-29 better PDN zones
    [LEVIA_H7.kicad_pcb]
2026-06-29 nextpcb manufacturing files updated
    [ANALOG_VTX.kicad_sch, BUZZER.kicad_sch, CAN.kicad_sch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]
2026-06-29 added ibom and other csv prod files
    [BOM-LEVIA_H7.csv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]
2026-06-30 DFA first round
    [CAN.kicad_sch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]
